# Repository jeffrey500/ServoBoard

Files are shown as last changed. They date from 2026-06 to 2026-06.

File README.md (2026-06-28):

# ServoBoard V2.1
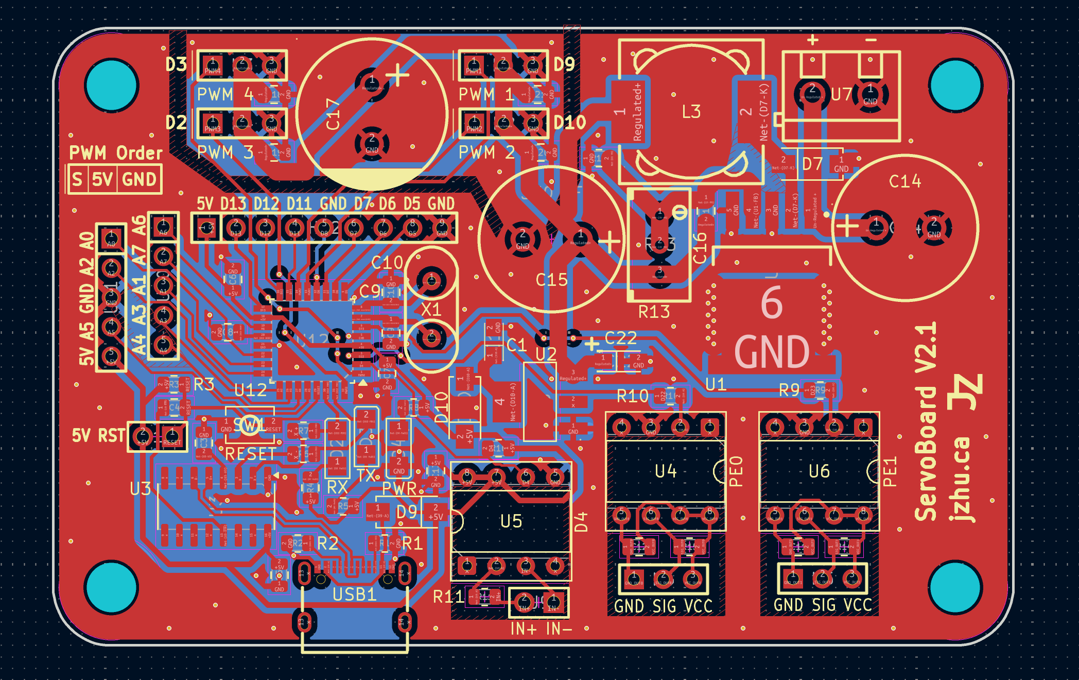
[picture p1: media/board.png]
board pcb
  
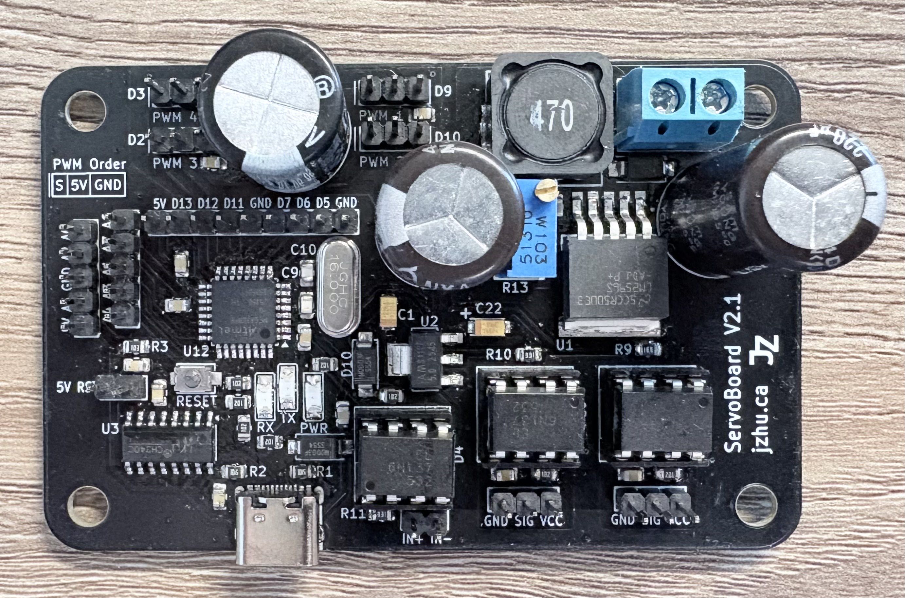
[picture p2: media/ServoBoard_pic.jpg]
ServoBoard_pic


## Introduction
This project contains a 2 layer PCB that has the designed purpose of driving up to 4 PWM servo motors of variable input voltage, with the entire board itself being powered by a variable voltage.  
This board is controlled by an atmega328PB and has 6n137 optocouplers.

## Microcontroller
The microcontroller (MCU) on this board is the atmega328PB which can be programmed via the USB-C connection on the side of the board through the use of a CH340C USB-to-UART serial converter IC.  
The atmega328PB was chosen as it is a simple and stable MCU that can be programmed using the Arduino IDE, and is an upgrade over the atmega328.
The MCU utilizes an external 16 MHz crystal oscillator. 

Note: the USB connection can only be used after initial bootloader burning (see ISP section).

## Power
There are 3 different voltages present on the board: input, servo, and 5V. 

Using the LM2596S buck voltage regulator, the board can utilize a maximum of 3A at the output of the Buck regulator. 
The efficiency of the LM2596S 92%. The board accepts a voltage range of 40V and can step it down to 1.25V-35V.
You can adjust the output voltage of the LM2596S by adjusting the screw on the blue potentiometer.
The potentiometer acts as a voltage divider which alters the internal PWM duty cycle. 

The use of an AMS1117-5.0 fixed 5V low dropout linear voltage regulator further steps down the voltage from the servo voltage to 5V to power the MCU.
The dropout range is 1.3V with a max input voltage of 15V.

Note: you should be careful when adjusting output of the LM2596S when using voltages higher than 15V as you can potentially destroy the AMS1117 LDO.
Additionally, the servo voltage should be high enough such that the MCU after the LDO has sufficient a sufficient voltage.

## Servo PWM pins
Servo motors can be driven using one or many of the 4 sets of SIGNAL-POWER-GROUND male header pins. 
The connected servo motors are driven by the voltage output of the LM2596S Buck Converter. 
A large 2200uF capacitor is placed very close to the servo pin headers to provide power during momentary high current draw. 

## Optocouplers
The Board contains 3 6n137 high-speed digital Optocouplers, mounted on DIP-8 sockets, allowing for interfacing with optical isolation.
The 6n137 mounted on the U5 DIP-8 socket is oriented as an input for digital signals while U4 and U6 are oriented as outputs.

## Board Design
This Board utilizes a 2 layer stackup. The top layer is signal with a ground pour.
The bottom layer is a ground plane of which effort was put in to ensure as much continuity as possible. 
The top and bottom ground layers are connected via stitching.
A power plane and cut is placed around the servo pin headers so that surges of power are drawn from the nearby capacitor.
Extra thermal vias are placed around the ground pin of the LM2596S.

## In-System Programming (ISP)
Following the assembly of the board you will need to do burn the bootloader of the board to be able to use the USB-C port to program the atmega328PB. 
To do this, it is recommended to use any Arduino in addition to its ability to be an [ISP flasher](https://docs.arduino.cc/built-in-examples/arduino-isp/ArduinoISP/).

### Schematic
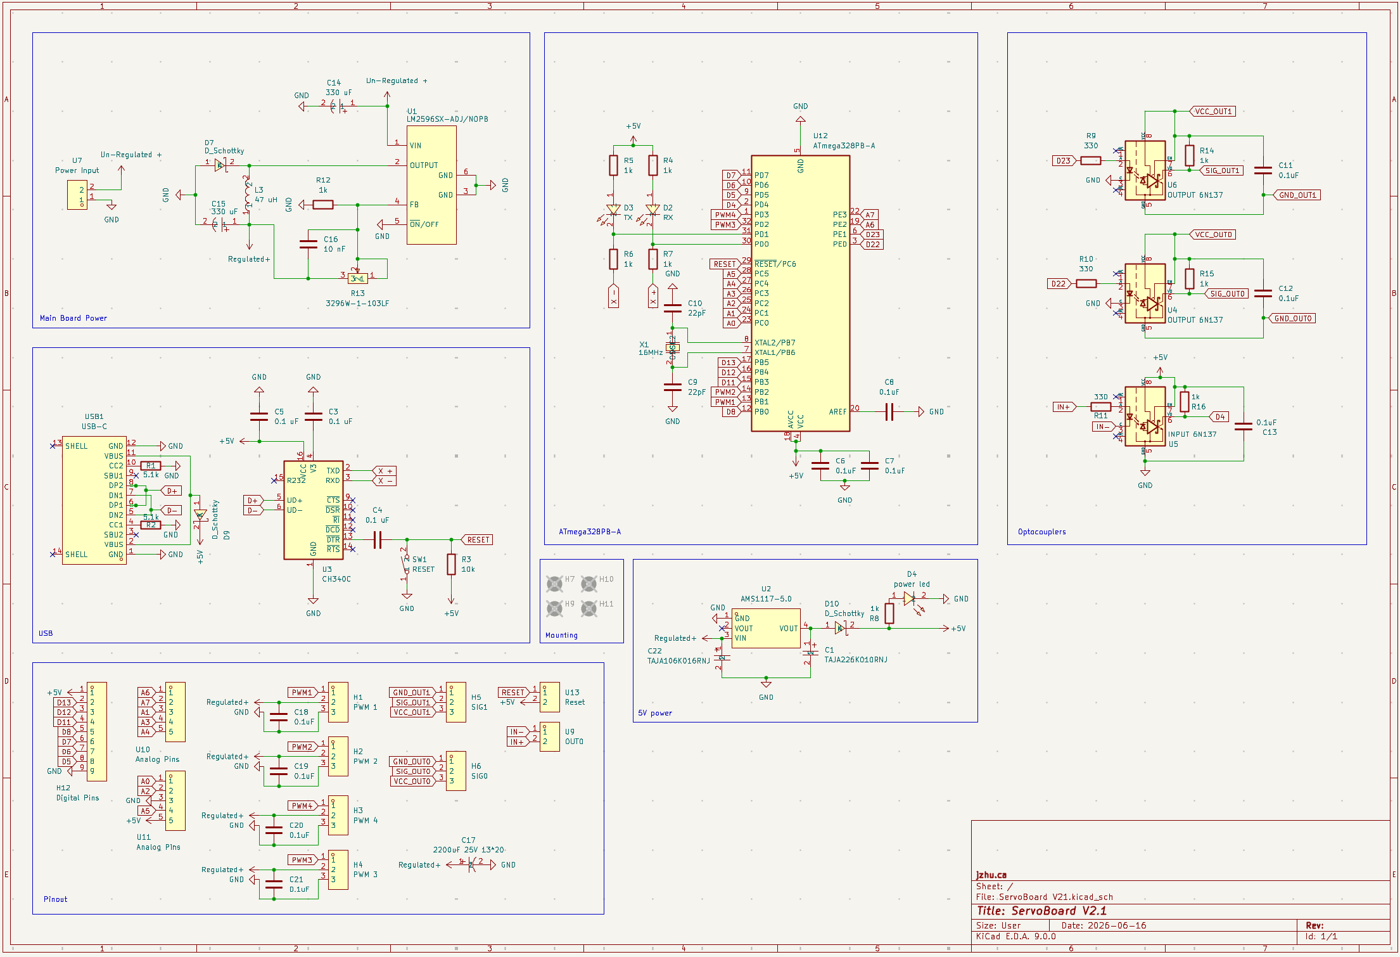
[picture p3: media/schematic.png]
ServoBoard Schematic


### Board Without Pours
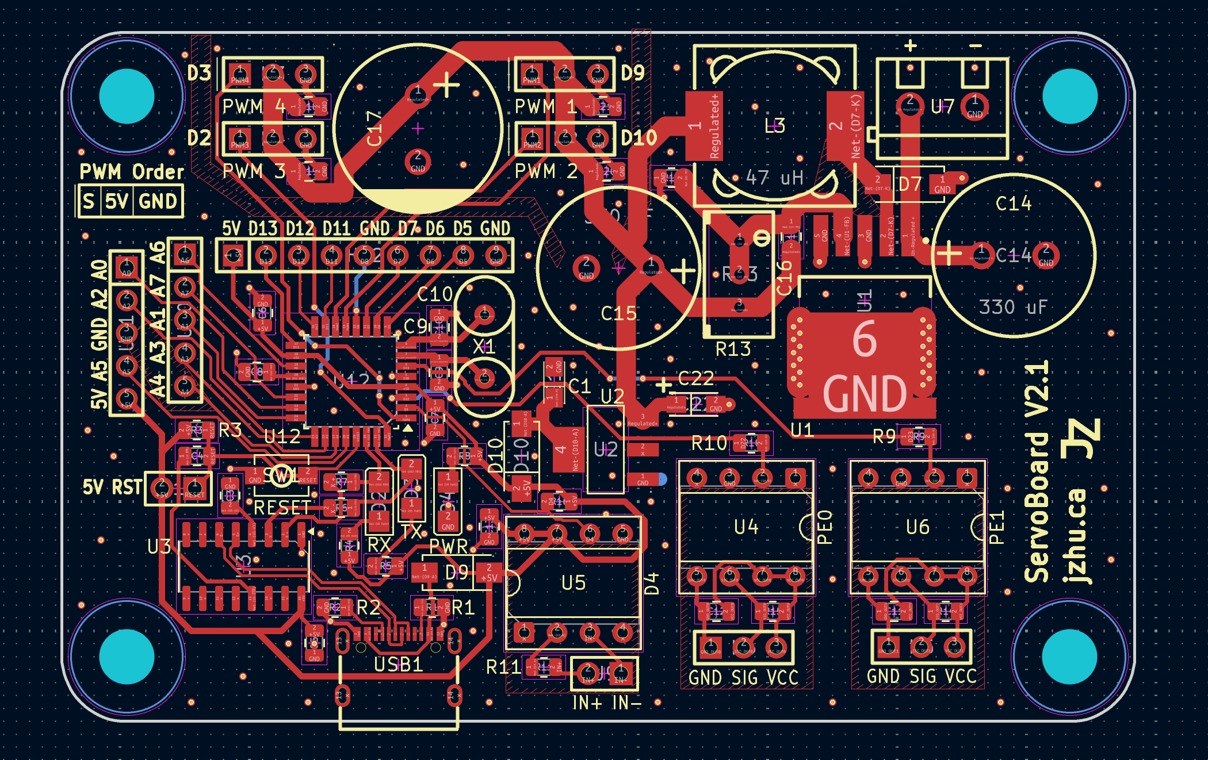
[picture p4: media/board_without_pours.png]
board_without_pours


### Top Copper
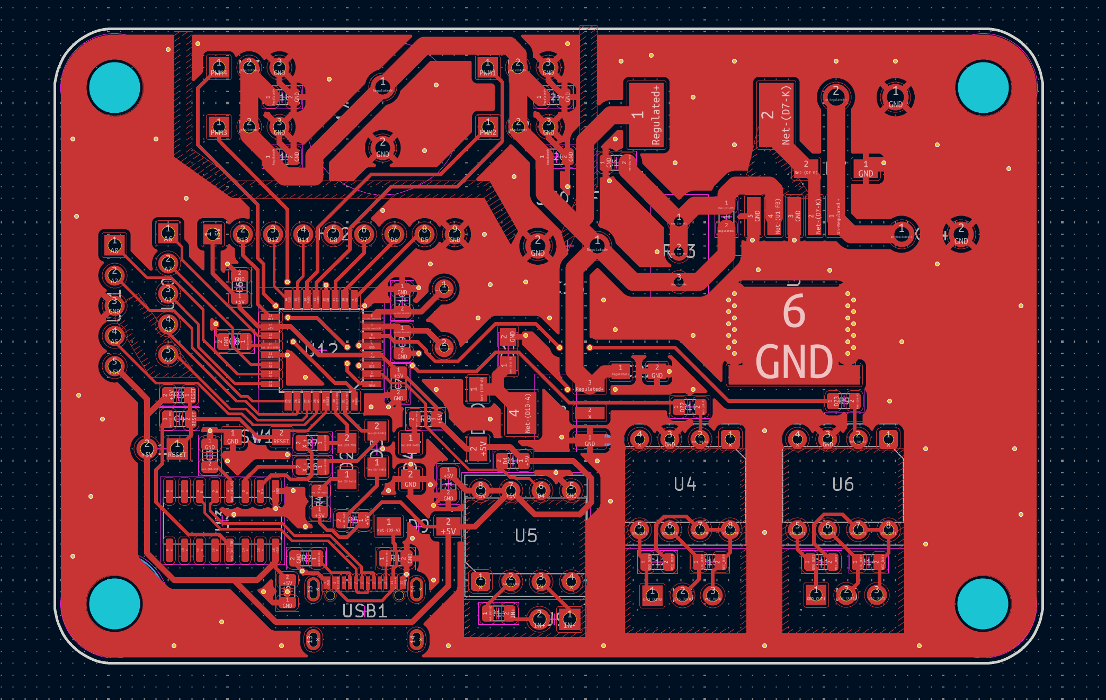
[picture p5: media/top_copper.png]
top_copper


### Bottom Copper
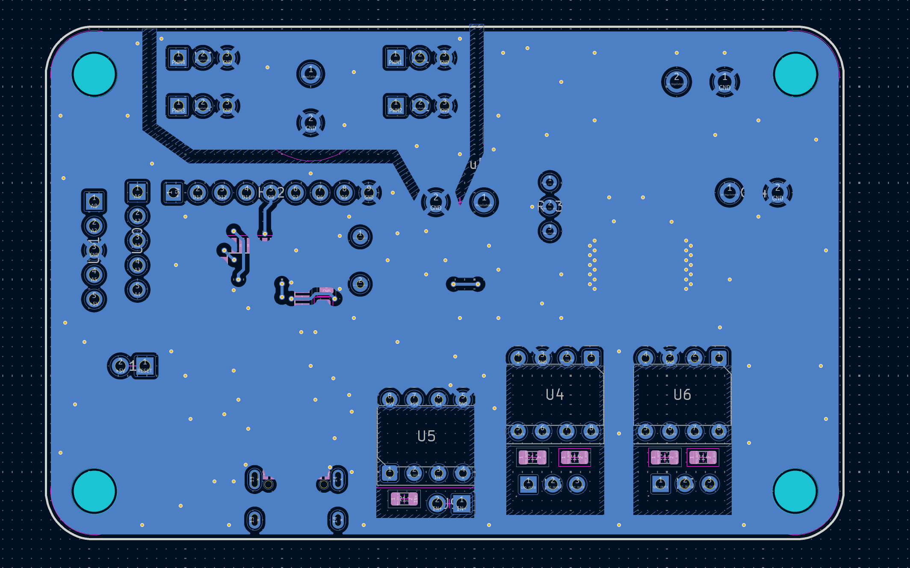
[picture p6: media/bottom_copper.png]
bottom_copper


## Application
The design application of this board is within a CNC White board plotter //add link for which this board controls a pen plotter that is controlled by an Ardunio CNC Shield, interfacing through an optocoupler.
The board input voltage is 12V, with the servo needing 7V.

## BOM
The cost of each board at low production quantities is around $15 CAD.

## LICENSE
[ServoBoard](https://github.com/jeffrey500/ServoBoard) © 2026 by [Jeffrey Zhu](https://jzhu.ca) is licensed under [CC BY-NC 4.0](https://creativecommons.org/licenses/by-nc/4.0/)



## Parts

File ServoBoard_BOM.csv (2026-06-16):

Part | Purpose | Quanity | Total Cost | LCSC
HX PZ2.54-1x3P ZZ | 3-Pin Header | 6 | $0.14 | C32713269 | Note: Some components quanities are less than the minimum order quanitiy
KF301-5.0-2P | 2-Pin Terminal Screw Block | 1 | $0.09 | C474881
TYPE-C 16PIN 2MD(073) | USB-C Port | 1 | $0.06 | C2765186
YLED1206R | Red Led | 3 | $0.03 | C28310439
NXA100V220M12.5*25 LO | 220uF Capacitor | 2 | $0.83 | C2835679
CDRH127N-470M | 47uH Inductor | 1 | $0.27 | C962356
SS54 | Diode | 3 | $0.13 | C22452
49SAC16000182060 | Crystal | 1 | $0.07 | C443538
HX PZ2.54-1x2P ZZ | 2-Pin Header | 1 | $0.02 | C32713268
HX PZ2.54-1x5P ZZ | 5-Pin Header | 2 | $0.08 | C32713271
1-2199298-2 | DIP-8 Socket | 3 | $0.65 | C305904
ATMEGA328PB-AU | atmega328PB | 1 | $1.65 | C132230
LM2596SX-ADJ/NOPB | LM2596S | 1 | $1.08 | C29781
3296W-1-103LF | Potentiometer | 1 | $0.79 | C34846
AMS1117-5.0 | 5V LDO | 1 | $0.24 | C6187
KM228M025J20RR0VH2FP0 | 2200uF Capacitor | 1 | $0.14 | C44598
TAJA106K016RNJ | 10uF Tantalum Capacitor | 1 | $0.13 | C7171
TAJA226K010RNJ | 22uF Tantalum Capacitor | 1 | $0.24 | C11366
CH340C | CH340C | 1 | $0.58 | C84681
6N137 | 6N137 | 3 | $0.64 | C142297
HX PZ2.54-1x9P ZZ | 9-Pin Header | 1 | $0.06 | C42372501
TS342A2P-WZ | Tactile Switch | 1 | $0.04 | C557591
GRM2195C1H103JA01D | 10nF Ceramic Capacitor | 20 | $0.85 | C97905 | Note: SMD resistors and Capacitors prices by minium order quanitity
FRC0805J102 TS | 1k ohm Resistor | 100 | $0.13 | C2907295
CL21B104KBCNNNC | 100nF Cermaic Capacitor | 100 | $0.65 | C1711
C0805C220J5RAC7800 | 22pF Cermaic Capacitor | 20 | $0.54 | C2176714
0805W8F5101T5E | 5.1k ohm Resistor | 100 | $0.19 | C27834
FRC0805J103TS | 10k ohm Resistor | 100 | $0.13 | C2930231
FRC0805J331 TS | 330 ohm Resistor | 100 | $0.14 | C2907321
 |  | Total: | $10.55 | USD

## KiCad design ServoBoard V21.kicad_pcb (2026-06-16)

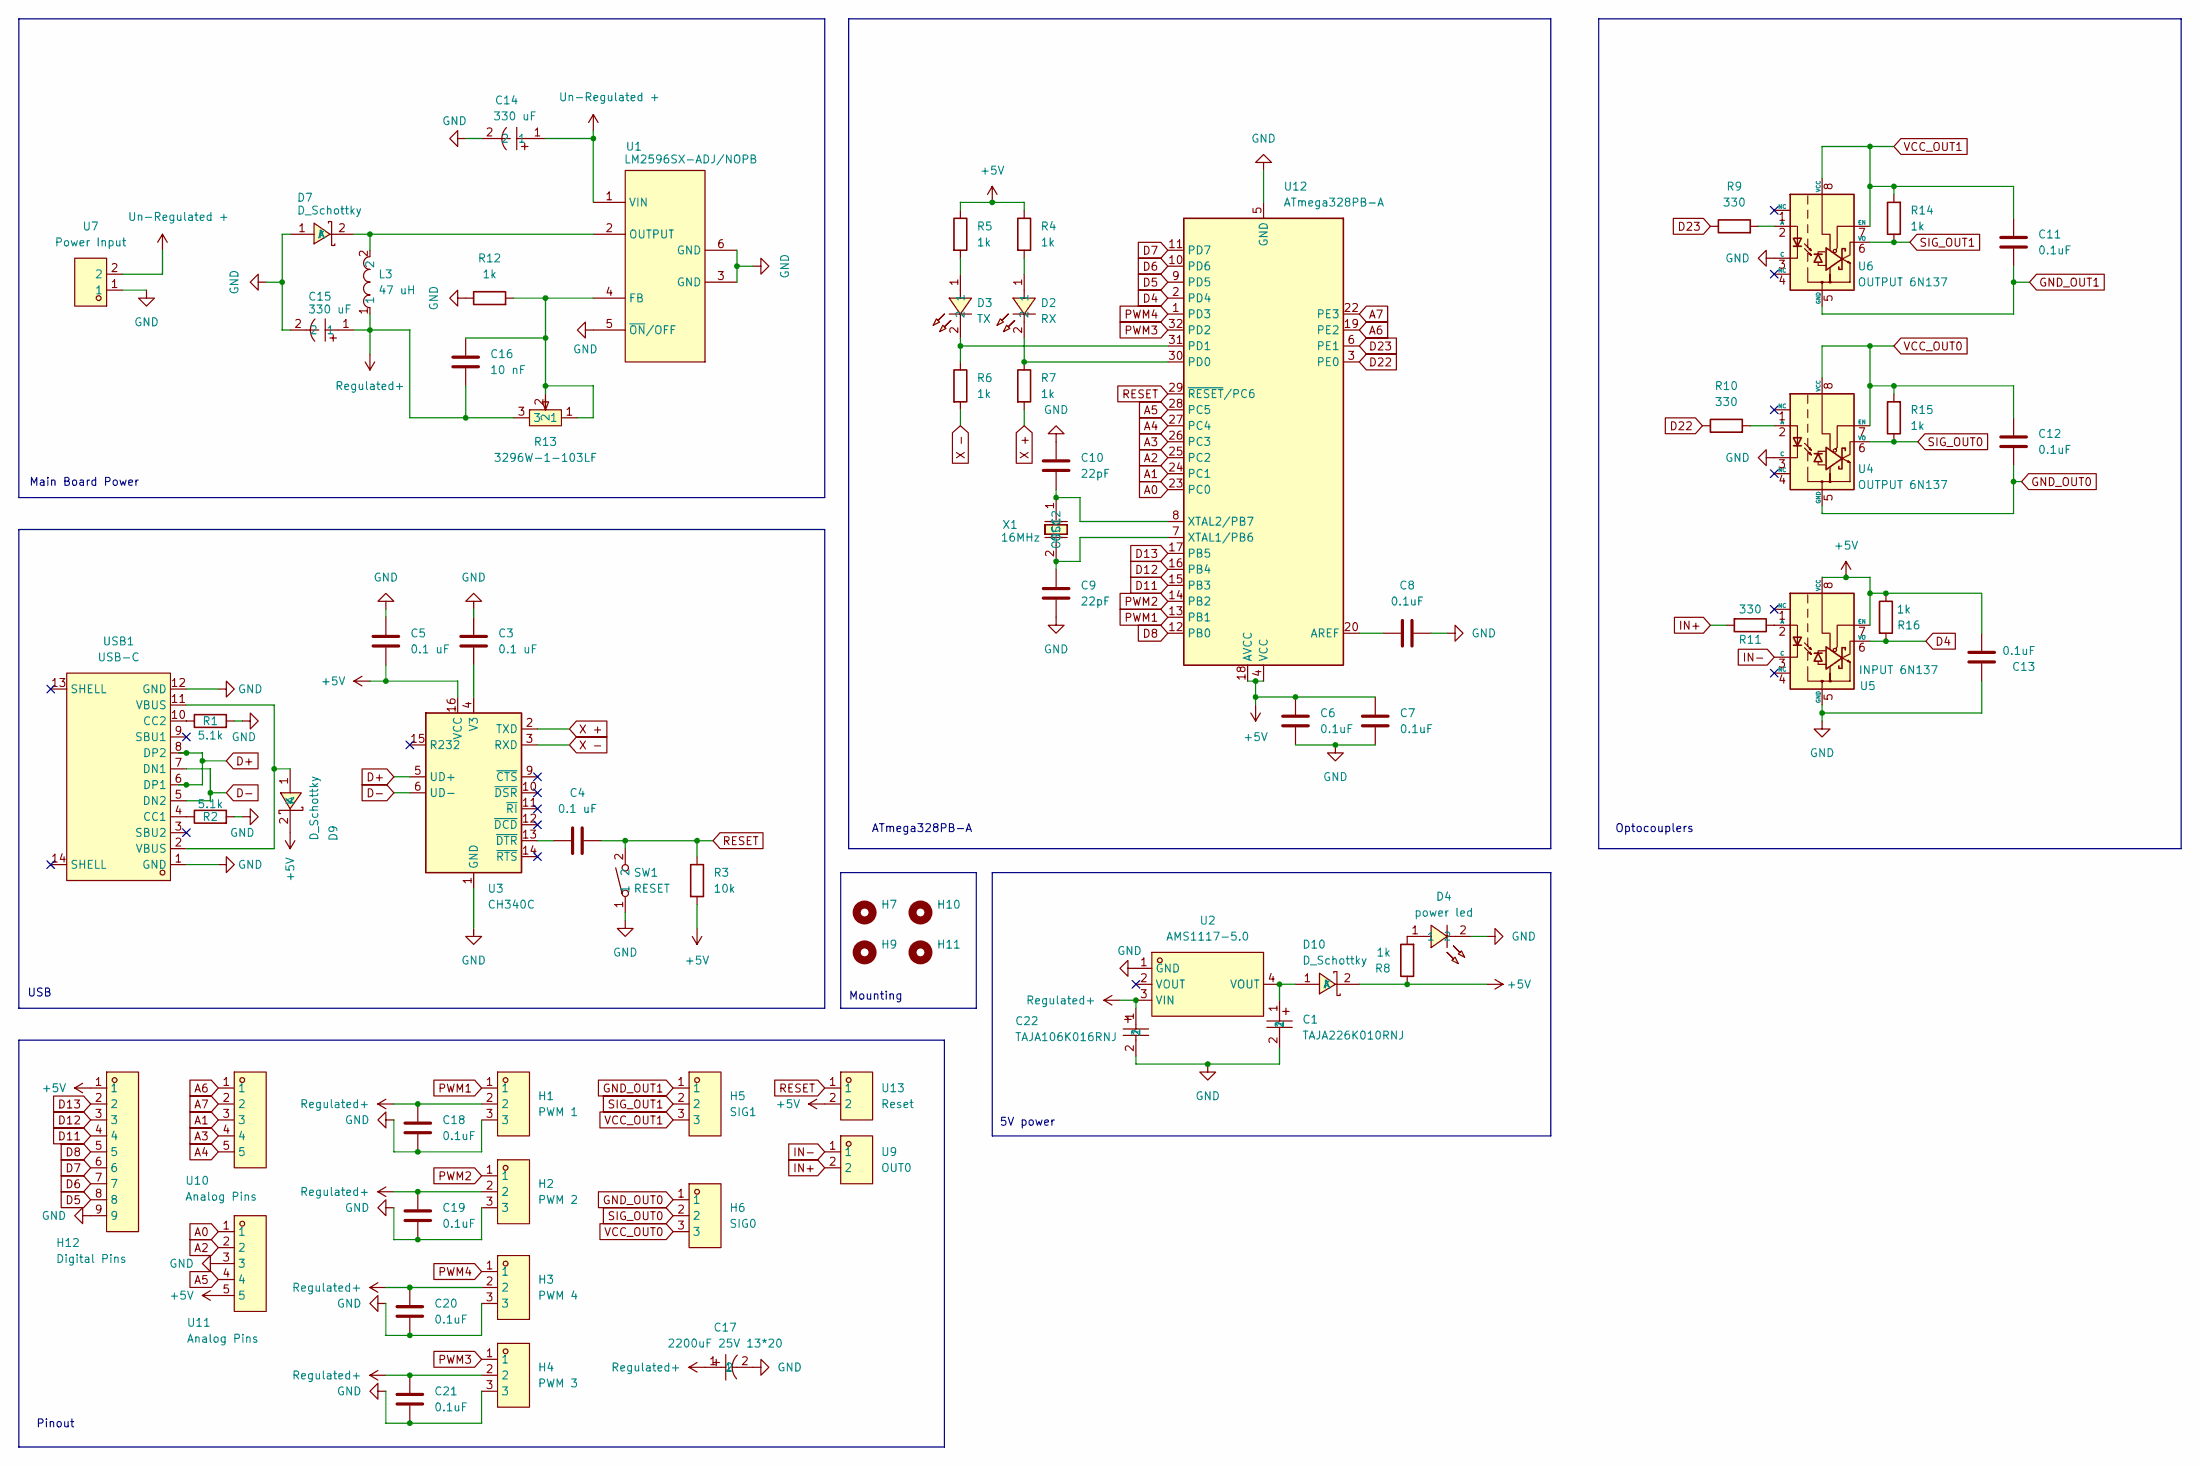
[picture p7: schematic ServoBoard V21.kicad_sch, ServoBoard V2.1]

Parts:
C1: TAJA226K010RNJ; CASE-A_3216; MPN TAJA226K010RNJ; LCSC Part C11366
C3, C4, C5: 0.1 uF; C_0805_2012Metric
C6, C7, C8, C11, C12, C13, C18, C19, C20, C21: 0.1uF; C_0805_2012Metric
C9, C10: 22pF; C_0805_2012Metric
C14, C15: 330 uF; CAP-TH_BD12.5-P5.00-D0.6-FD; LCSC Part C2835679
C16: 10 nF; C_0805_2012Metric
C17: 2200uF 25V 13*20; CAP-TH_BD13.0-P5.00-D1.2-FD; MPN KM228M025J20RR0VH2FP0; LCSC Part C44598
C22: TAJA106K016RNJ; CAP-SMD_L3.2-W1.6-RD-C7171; MPN TAJA106K016RNJ; LCSC Part C7171
D2: RX; LED1206-FD; LCSC Part C28310439
D3: TX; LED1206-FD; LCSC Part C28310439
D4: power led; LED1206-FD; LCSC Part C28310439
D7, D9, D10: D_Schottky; SMA_L4.4-W2.8-LS5.4-R-RD; LCSC Part C22452
H1: PWM 1; CONN-TH_HX-PZ2.54-1X3P-ZZ; LCSC Part C32713269
H2: PWM 2; CONN-TH_HX-PZ2.54-1X3P-ZZ; LCSC Part C32713269
H3: PWM 4; CONN-TH_HX-PZ2.54-1X3P-ZZ; LCSC Part C32713269
H4: PWM 3; CONN-TH_HX-PZ2.54-1X3P-ZZ; LCSC Part C32713269
H5: SIG1; CONN-TH_HX-PZ2.54-1X3P-ZZ; LCSC Part C32713269
H6: SIG0; CONN-TH_HX-PZ2.54-1X3P-ZZ; LCSC Part C32713269
H7, H9, H10, H11: MountingHole; MountingHole_4.3mm_M4
H12: Digital Pins; HDR-TH_9P-P2.54-V-F-3; LCSC Part C42372501
L3: 47 uH; IND-SMD_L12.3-W12.3; LCSC Part C962356
R1, R2: 5.1k; R_0805_2012Metric
R3: 10k; R_0805_2012Metric
R4, R5, R6, R7, R8, R12, R14, R15, R16: 1k; R_0805_2012Metric
R9, R10, R11: 330; R_0805_2012Metric
R13: 3296W-1-103LF; RES-ADJ-TH_3296W; MPN 3296W-1-103LF; LCSC Part C34846
SW1: RESET; SW-SMD_L4.0-W2.9-LS5.0; LCSC Part C557591
U1: LM2596SX-ADJ/NOPB; TO-263-5_L10.2-W8.9-P1.70-TL; MPN LM2596SX-ADJ/NOPB; LCSC Part C29781
U2: AMS1117-5.0; SOT-223_L6.5-W3.5-P2.30-LS7.0-BR; MPN AMS1117-5.0; LCSC Part C6187
U3: CH340C; SOIC-16_3.9x9.9mm_P1.27mm
U4, U6: OUTPUT 6N137; DIP-8_W7.62mm_Socket
U5: INPUT 6N137; DIP-8_W7.62mm_Socket
U7: Power Input; CONN-TH_P5.00_KF301-5.0-2P; LCSC Part C474881
U9: OUT0; HDR-TH_2P-P2.54-V-M-3; LCSC Part C32713268
U10, U11: Analog Pins; HDR-TH_5P-P2.54-V-M; LCSC Part C32713271
U12: ATmega328PB-A; TQFP-32_7x7mm_P0.8mm
U13: Reset; HDR-TH_2P-P2.54-V-M-3; LCSC Part C32713268
USB1: USB-C; USB-C-SMD_TYPE-C-6PIN-2MD-073; LCSC Part C2765186
X1: 16MHz; OSC-TH_L10.0-W4.5-P5.00; LCSC Part C443538

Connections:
+5V: C5.2, C6.1, C7.1, C13.1, D9.2 (K), D10.2 (K), H12.1, R3.2, R4.1, R5.1, R8.1, R16.1, U3.16 (VCC), U5.7 (EN), U5.8 (VCC), U11.5, U12.4 (VCC), U12.18 (AVCC), U13.2
A0: U11.1, U12.23 (PC0)
A1: U10.3, U12.24 (PC1)
A2: U11.2, U12.25 (PC2)
A3: U10.4, U12.26 (PC3)
A4: U10.5, U12.27 (PC4)
A5: U11.4, U12.28 (PC5)
A6: U10.1, U12.19 (PE2)
A7: U10.2, U12.22 (PE3)
D4: R16.2, U5.6 (VO), U12.2 (PD4)
D5: H12.8, U12.9 (PD5)
D6: H12.7, U12.10 (PD6)
D7: H12.6, U12.11 (PD7)
D8: H12.5, U12.12 (PB0)
D11: H12.4, U12.15 (PB3)
D12: H12.3, U12.16 (PB4)
D13: H12.2, U12.17 (PB5)
D22: R10.1, U12.3 (PE0)
D23: R9.1, U12.6 (PE1)
D+: U3.5 (UD+), USB1.6 (DP1), USB1.8 (DP2)
D-: U3.6 (UD-), USB1.5 (DN2), USB1.7 (DN1)
GND: C1.2, C3.1, C5.1, C6.2, C7.2, C8.2, C9.2, C10.1, C13.2, C14.2, C15.2, C17.2, C18.2, C19.2, C20.2, C21.2, C22.2, D4.2, D7.1 (A), H1.3, H2.3, H3.3, H4.3, H12.9, R1.2, R2.2, R12.1, SW1.1, U1.3 (GND), U1.5 (~ON/OFF), U1.6 (GND), U2.1 (GND), U3.1 (GND), U4.3 (C), U5.5 (GND), U6.3 (C), U7.1, U11.3, U12.5 (GND), U12.21 (GND), USB1.1 (GND), USB1.12 (GND)
GND_OUT0: C12.1, H6.1, U4.5 (GND)
GND_OUT1: C11.1, H5.1, U6.5 (GND)
IN+: R11.2, U9.2
IN-: U5.3 (C), U9.1
unnamed: D2.1, R4.2
unnamed: D3.1, R5.2
unnamed: D4.1, R8.2
unnamed: D7.2 (K), L3.2, U1.2 (OUTPUT)
unnamed: D9.1 (A), USB1.2 (VBUS), USB1.11 (VBUS)
unnamed: C1.1, D10.1 (A), U2.4 (VOUT)
unnamed: C16.1, R12.2, R13.1, R13.2, U1.4 (FB)
unnamed: C3.2, U3.4 (V3)
unnamed: C4.1, U3.13 (~DTR)
unnamed: R10.2, U4.2 (A)
unnamed: R11.1, U5.2 (A)
unnamed: R9.2, U6.2 (A)
unnamed: C8.1, U12.20 (AREF)
unnamed: D2.2, R7.1, U12.30 (PD0)
unnamed: D3.2, R6.1, U12.31 (PD1)
unnamed: C9.1, U12.7 (XTAL1/PB6), X1.2 (OSC2)
unnamed: C10.2, U12.8 (XTAL2/PB7), X1.1 (OSC1)
unnamed: R2.1, USB1.4 (CC1)
unnamed: R1.1, USB1.10 (CC2)
PWM1: H1.1, U12.13 (PB1)
PWM2: H2.1, U12.14 (PB2)
PWM3: H4.1, U12.32 (PD2)
PWM4: H3.1, U12.1 (PD3)
RESET: C4.2, R3.1, SW1.2, U12.29 (~RESET/PC6), U13.1
Regulated+: C15.1, C16.2, C17.1, C18.1, C19.1, C20.1, C21.1, C22.1, H1.2, H2.2, H3.2, H4.2, L3.1, R13.3, U2.3 (VIN)
SIG_OUT0: H6.2, R15.1, U4.6 (VO)
SIG_OUT1: H5.2, R14.1, U6.6 (VO)
Un-Regulated +: C14.1, U1.1 (VIN), U7.2
VCC_OUT0: C12.2, H6.3, R15.2, U4.7 (EN), U4.8 (VCC)
VCC_OUT1: C11.2, H5.3, R14.2, U6.7 (EN), U6.8 (VCC)
X +: R7.2, U3.2 (TXD)
X -: R6.2, U3.3 (RXD)

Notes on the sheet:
USB
ATmega328PB-A
5V power
Optocouplers
Pinout
Main Board Power
Mounting

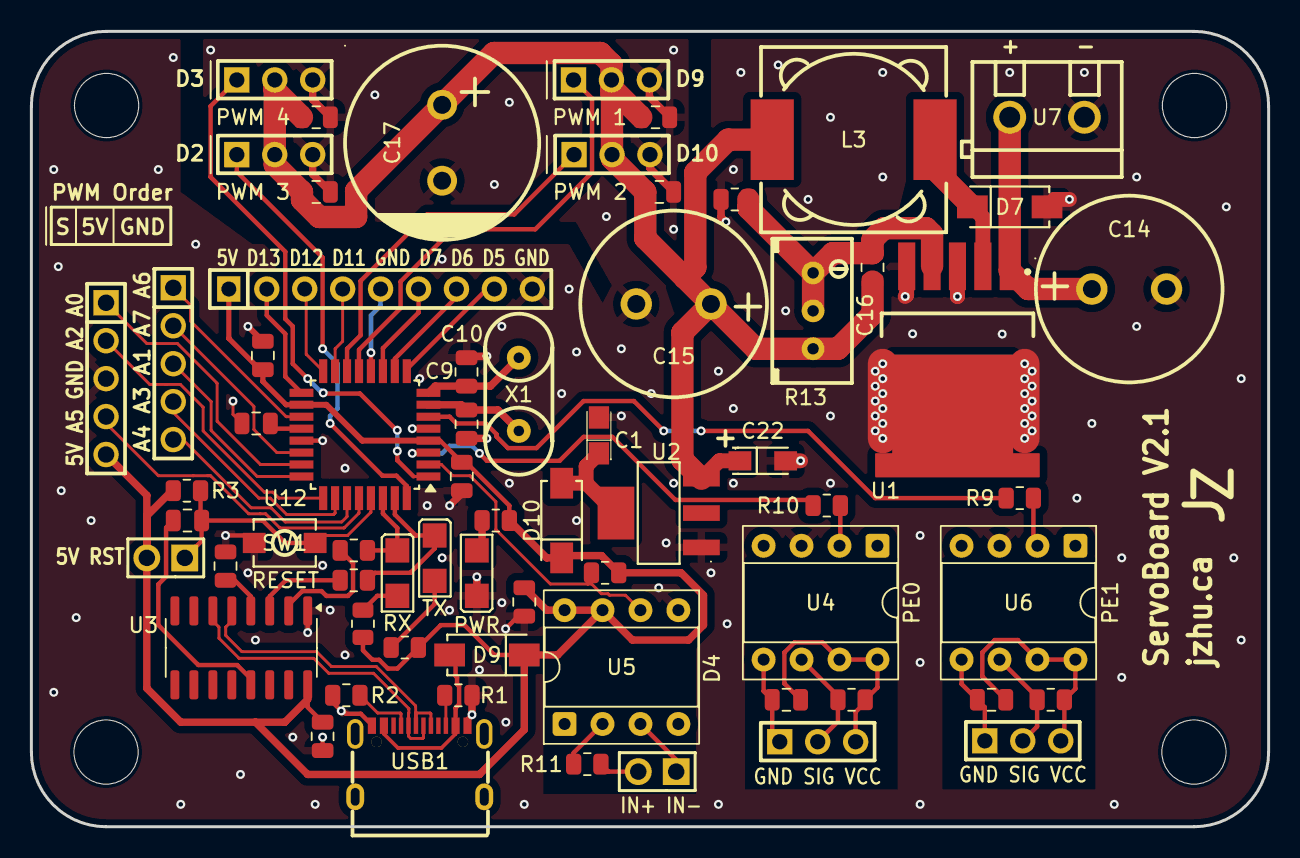
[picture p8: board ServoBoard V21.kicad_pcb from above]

Board: 2 copper layers, 82.8 x 53.2 mm, 70 parts (0 on the bottom side), 58 nets.

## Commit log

2026-06-28 Added final IRL PCB picture
2026-06-28 added IRL ServoBoard_pic.jpg
